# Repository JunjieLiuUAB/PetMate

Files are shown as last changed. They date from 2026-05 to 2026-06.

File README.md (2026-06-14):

# 🐾 PetMate

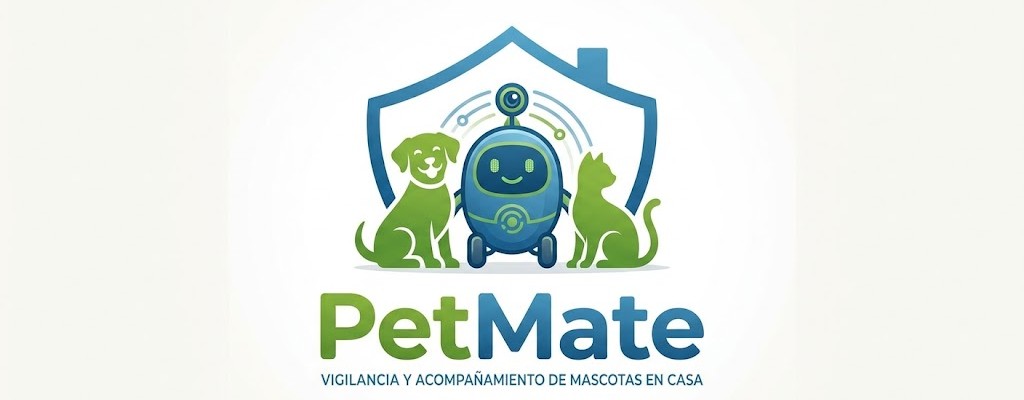
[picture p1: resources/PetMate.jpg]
PetMate Robot






[]()

> **Robot autónomo inteligente** para la vigilancia, seguridad y bienestar de tus mascotas cuando no estás en casa.

PetMate patrulla tu hogar de forma autónoma, detecta y clasifica el tipo de mascota, estima su pose en tiempo real, dispensa premios por buen comportamiento y te permite interactuar con ella a distancia desde una aplicación móvil.

---

## Tabla de Contenidos

1. [Descripción General](#descripción-general)
2. [Características Principales](#características-principales)
3. [Demo](#demo)
4. [Hardware y Componentes](#hardware-y-componentes)
   - [4.1. Componentes](#componentes)
   - [4.2. Arquitectura del Hardware](#arquitectura-del-hardware)
5. [Software y Visión Artificial](#software-y-visión-artificial)
   - [5.1. Arquitectura del Software](#arquitectura-del-software)
   - [5.2. Visión Artificial](#visión-artificial)
6. [Algoritmo de Navegación](#algoritmo-de-navegación)
7. [Instalación y Configuración](#instalación-y-configuración)
8. [Estructura del Repositorio](#estructura-del-repositorio)
9. [Referencias](#referencias)
10. [Contribuidores](#contribuidores)
11. [Licencia](#licencia)

---

## Descripción General

**PetMate** es un robot móvil autónomo diseñado para monitorizar mascotas en entornos domésticos. Combina visión artificial, Deep Learning y navegación autónoma sobre una plataforma Raspberry Pi 4 para ofrecer:

- **Vigilancia continua** de tu mascota mientras no estás en casa.
- **Identificación** del tipo de animal y **clasificación de su pose** (de pie, sentado, tumbado).
- **Interacción remota** mediante una app móvil: visualización en directo y envío de audios.
- **Dispensación de premios** automática por buen comportamiento (p. ej., sentarse a la orden).
- **Patrullaje autónomo** con evasión de obstáculos mediante algoritmo *Wall Following*.
- **Autonomía energética** gracias a un panel solar integrado.

#### Modelo 3D

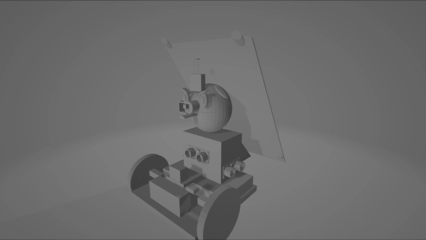
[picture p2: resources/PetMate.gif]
<p>

---

## Características Principales

| Característica | Detalle |
|---|---|
| **Detección de mascotas** | Clasificación del tipo de animal en tiempo real con modelo de Deep Learning |
| **Estimación de pose** | Detecta si la mascota está de pie, sentada o tumbada |
| **Navegación autónoma** | Algoritmo *Wall Following* implementado con 3 sensores ultrasónicos HC-SR04 |
| **Evasión de obstáculos** | Detección frontal, izquierda y derecha para esquivar obstáculos dinámicos |
| **App remota** | Streaming de vídeo en directo y control de audio desde el móvil |
| **Altavoz integrado** | Reproducción de audios enviados desde la app o alertas automáticas |
| **Dispensador de premios** | Servo-actuado: dispensa una chuche cuando detecta la secuencia correcta de comportamiento |
| **Panel solar** | Recarga continua para vigilancia prolongada sin necesidad de enchufar el robot |
| **Modelo en la nube** | Inferencia y almacenamiento gestionados remotamente mediante el proyecto *PetWatch* |
| **Notificaciones instantáneas** | Notificaciones en tiempo real de lo que está haciendo la mascota a través de la app |

---

## Demo

Vídeo demostrativo del robot PetMate en funcionamiento con todas sus funcionalidades

> **[Vídeo del robot PetMate en funcionamiento](https://drive.google.com/file/d/18QyB4_ARn3ffCMrifwrO2AGSIk0D8yak/view?usp=drive_link)** 

---

## Hardware y Componentes

En esta sección se detalla el hardware y los componentes del robot.

### Componentes

| Imagen | Componente | Unid. | Precio |
|:---:|:---|:---:|---:|
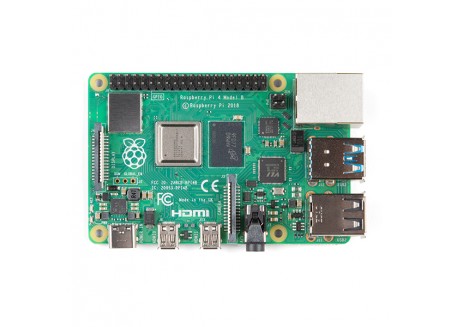
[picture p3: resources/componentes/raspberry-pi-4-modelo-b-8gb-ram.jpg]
Raspberry Pi 4
|  | Raspberry Pi 4 Modelo B — 8 GB RAM | 1 | 88,50 € |
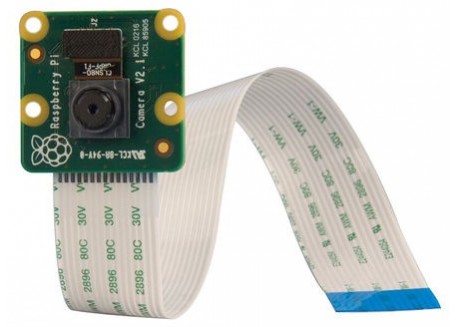
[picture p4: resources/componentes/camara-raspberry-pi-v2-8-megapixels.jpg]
Pi Camera
|  | Raspberry Pi Camera Module 2 (8 MP) | 1 | 19,95 € |
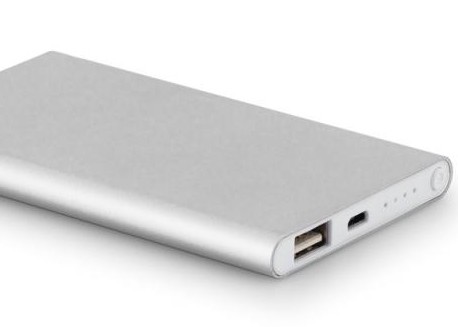
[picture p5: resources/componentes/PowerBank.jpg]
PowerBank
|  | PowerBank 10 000 mAh | 1 | 15,95 € |
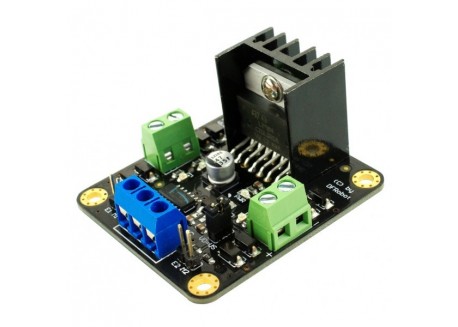
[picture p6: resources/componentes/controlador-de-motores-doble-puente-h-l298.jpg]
L298N
|  | Controlador de motores doble puente H — L298N | 1 | 15,50 € |
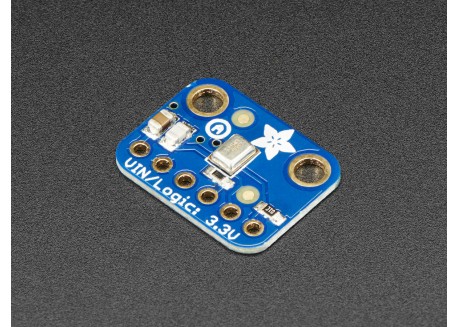
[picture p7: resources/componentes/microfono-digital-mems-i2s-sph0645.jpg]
Micrófono
|  | Micrófono electret preamplificado | 1 | 9,75 € |
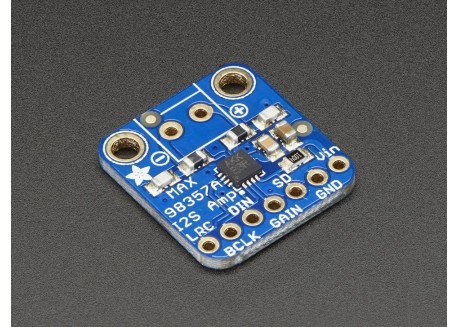
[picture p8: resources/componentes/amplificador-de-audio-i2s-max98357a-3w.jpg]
Amplificador
|  | Amplificador de audio I2s | 1 | 6,70 € |
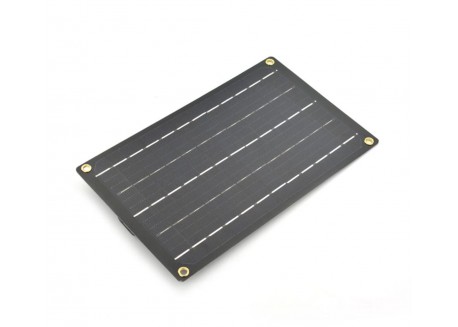
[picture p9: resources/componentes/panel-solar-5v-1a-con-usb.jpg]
Panel Solar
|  | Panel Solar 6 V / 1 W con cable | 1 | 9,95 € |
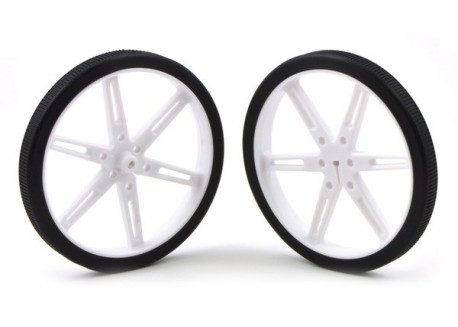
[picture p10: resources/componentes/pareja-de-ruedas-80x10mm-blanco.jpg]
Ruedas
|  | Pareja de ruedas 80×10 mm | 1 | 7,95 € |
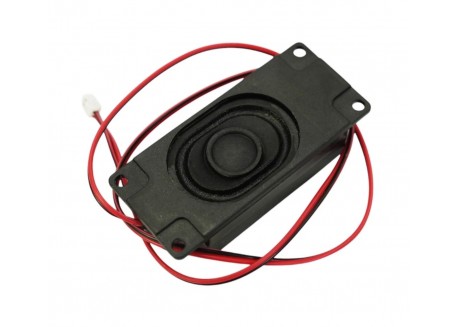
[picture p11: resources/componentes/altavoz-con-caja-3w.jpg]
Altavoz
|  | Altavoz con caja 3 W | 1 | 5,90 € |
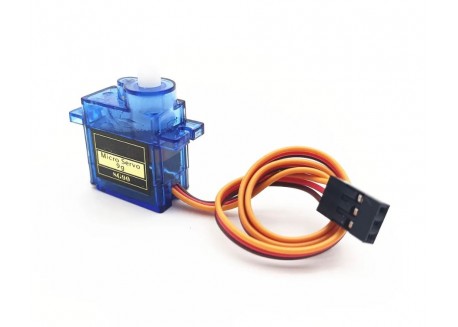
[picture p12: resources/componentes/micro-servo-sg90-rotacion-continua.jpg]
Servo
|  | Servo MG90S (dispensador) | 1 | 3,95 € |
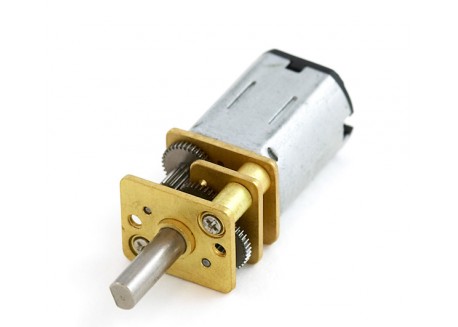
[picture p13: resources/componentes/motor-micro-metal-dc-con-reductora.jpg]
Motor
|  | Motor Micro Metal LP con reductora | 2 | 4,50 € |
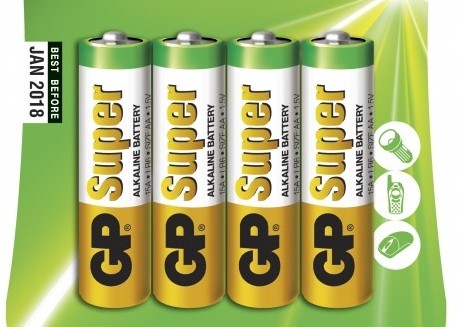
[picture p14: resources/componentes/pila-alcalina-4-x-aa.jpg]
Pilas
|  | Pilas Alcalinas 4×AA | 1 | 2,99 € |
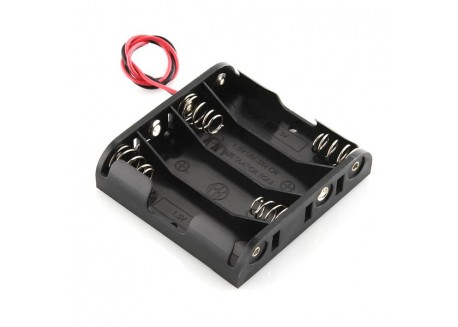
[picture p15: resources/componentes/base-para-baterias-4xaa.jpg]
Base pilas
|  | Base para pilas 4×AA | 1 | 2,00 € |
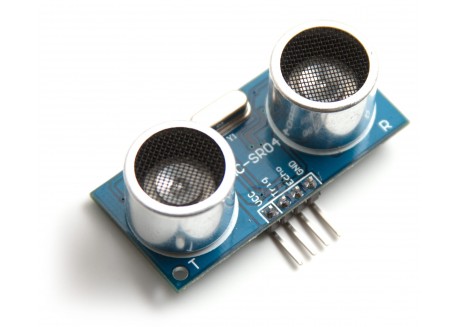
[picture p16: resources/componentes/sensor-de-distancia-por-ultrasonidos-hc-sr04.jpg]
HC-SR04
|  | Sensor ultrasónico HC-SR04 | 3 | 1,80 € |
| | | **TOTAL** | **203,49 €** |

El coste total estimado del hardware es de **203,49 €**.

### Arquitectura del Hardware

En este apartado se describe cómo se conecta todos los componentes hardware del robot para garantizar su correcto funcionamiento.

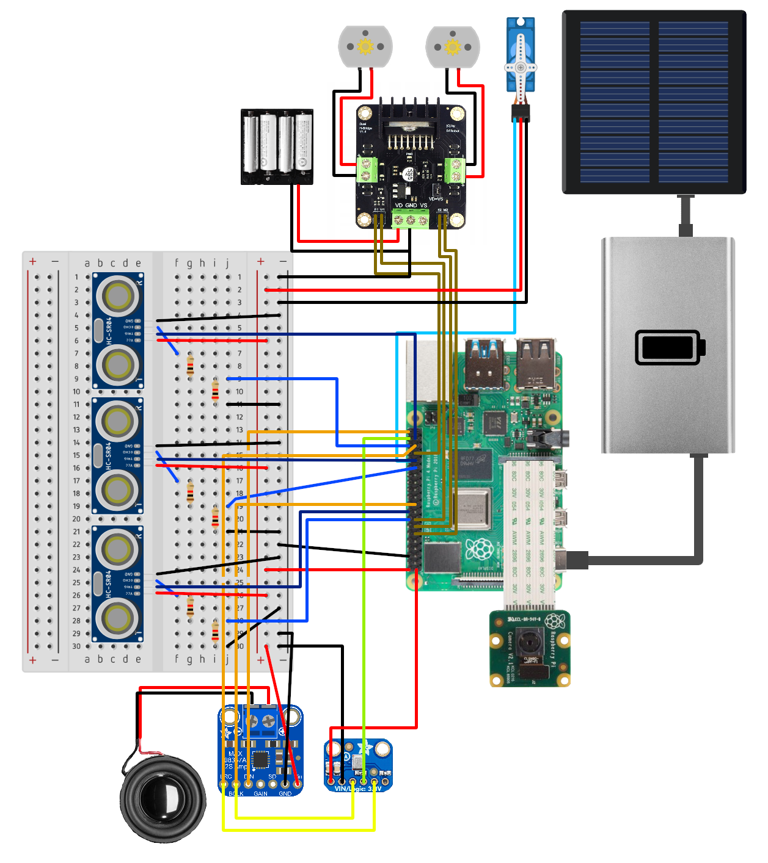
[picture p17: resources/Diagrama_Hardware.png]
Diagrama de la arquitectura del hardware


---

## Software y Visión Artificial

En esta sección se describe los detalles del software y la visión artifical de nuestro proyecto.

### Arquitectura del Software

En este apartado se detalla con un diagrama la arquitectura del software de los diversos módulos interconectados del robot, explicando cómo se comunica y colabora cada componente para garantizar el correcto funcionamiento de nuestro robot PetMate.

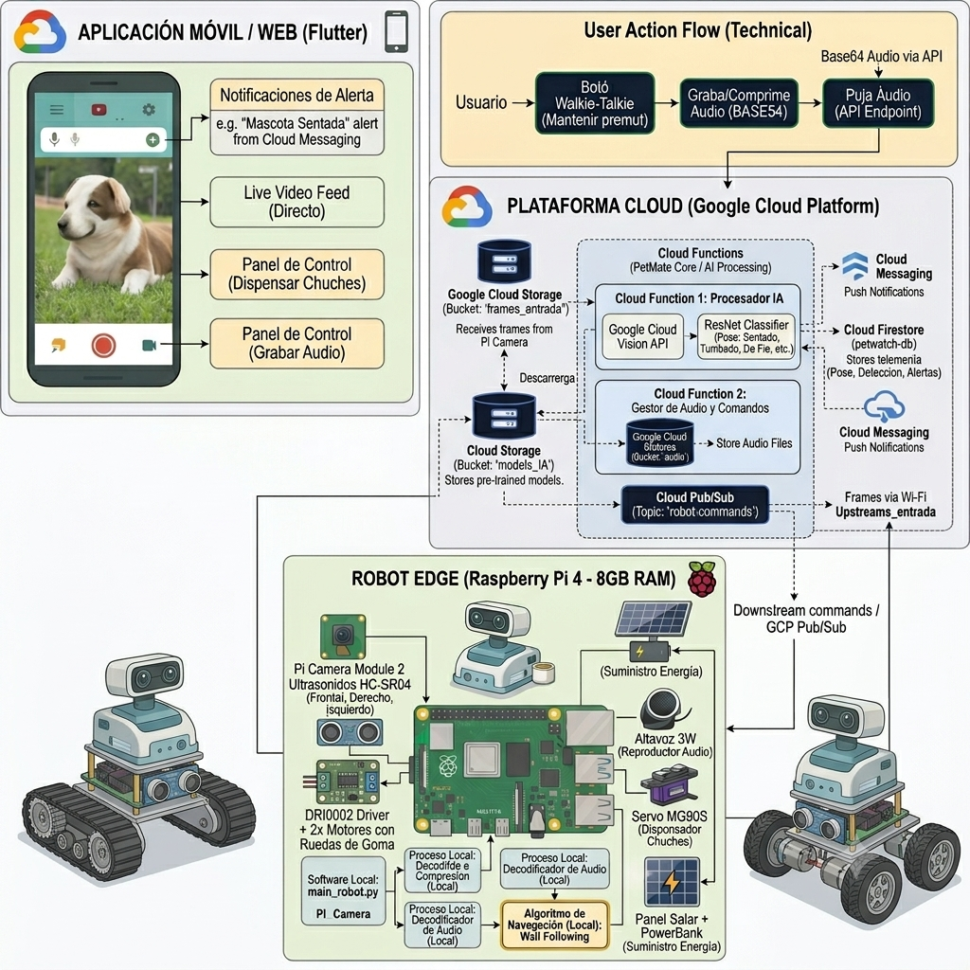
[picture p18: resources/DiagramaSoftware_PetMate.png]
Diagrama de la arquitectura de software


### Visión Artificial

El pipeline de visión artificial se estructura en dos etapas en cascada:

#### 1. Detección del tipo de mascota
- Modelo de detección de objetos entrenado con técnicas de **Deep Learning y YOLOv8** (También optamos por el uso de una Google Cloud Vision API para mejores resultados).
- Procesa el flujo de vídeo en tiempo real desde la **Pi Camera Module 2**.
- Clasifica el animal detectado (perro, gato, etc.).

#### 2. Estimación de pose
Una vez identificado el animal, un segundo modelo clasifica su estado postural:

| Pose | Descripción |
|---|---|
| De pie | El animal está erguido sobre sus patas |
| Sentado | El animal está sentado |
| Tumbado | El animal está estirado en el suelo |

#### Infraestructura Cloud — PetWatch

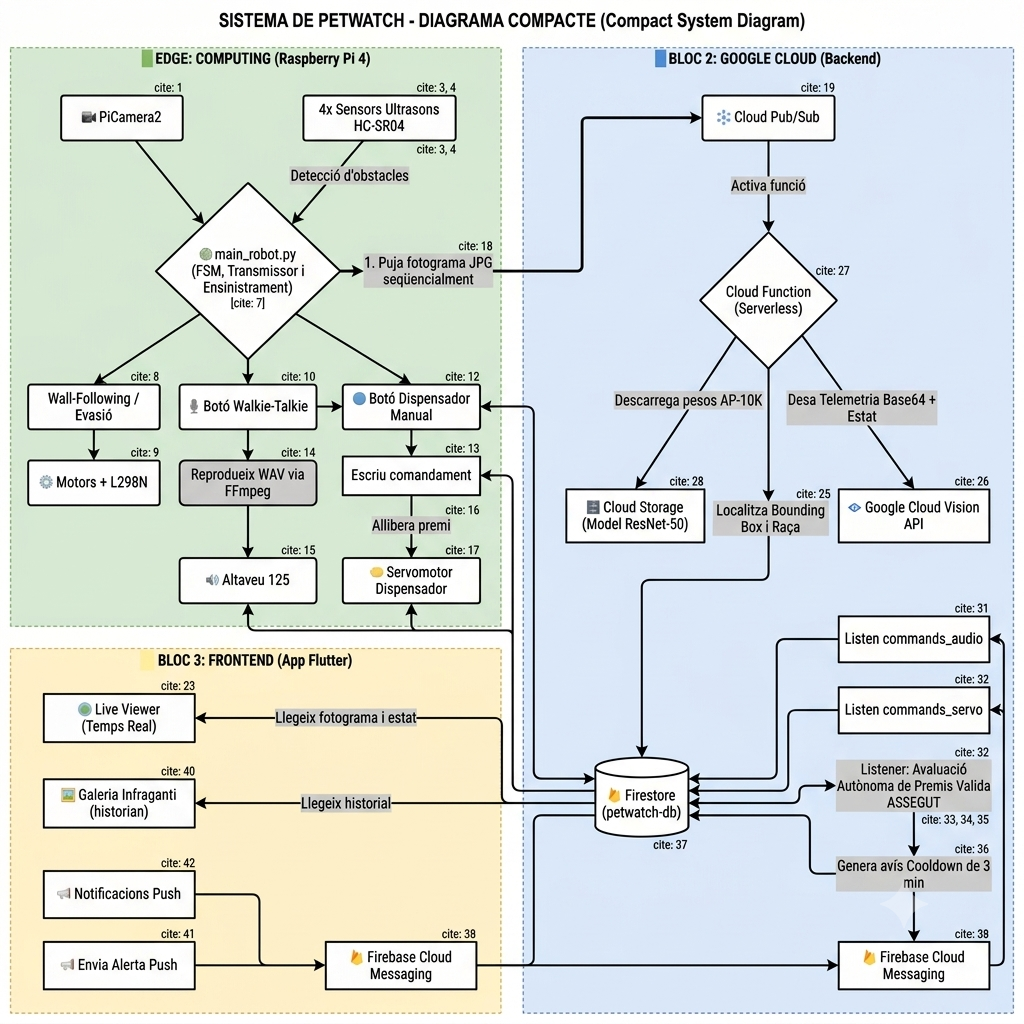
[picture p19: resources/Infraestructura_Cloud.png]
<p>
   
El modelo de inferencia está desplegado en la nube a través del proyecto **[PetWatch](📂 PetWatch)**, que también gestiona:
- Streaming de vídeo hacia la app móvil.
- Recepción y reproducción de audios enviados por el usuario.
- Almacenamiento de eventos y alertas.

**Stack tecnológico:**
* **Robot Edge (Raspberry Pi 4):** `picamera2` (captura de vídeo), `opencv-python` (compresión de frames y decodificación de audio), `RPi.GPIO` (control de motores DRI0002, servo y sensores HC-SR04) y `numpy`.
* **Plataforma Cloud (GCP & Firebase):** `functions-framework` (Cloud Functions), `torch` y `torchvision` (Inferencia YOLOv8 y ResNet), `google-cloud-pubsub` (comandos en tiempo real), `google-cloud-storage` (buckets de imágenes/audios) y `google-cloud-firestore` / `firebase-admin` (base de datos y alertas).

---

## Algoritmo de Navegación

PetMate implementa un algoritmo de **Wall Following** para patrullar el hogar de forma estructurada:

```
┌─────────────────────────────────────────────────────────────┐
│                   LÓGICA DE NAVEGACIÓN                      │
│                                                             │
│  ┌──────────────────────────────────────────────────────┐   │
│  │ Sensor DERECHO detecta pared                         │   │
│  │                                                      │   │
│  │  · Demasiado cerca  →  Ajustar: girar a la izquierda │   │
│  │  · Distancia ideal  →  Seguir recto                  │   │
│  │  · Demasiado lejos  →  Ajustar: girar a la derecha   │   │
│  └──────────────────────────────────────────────────────┘   │
│                                                             │
│  ┌──────────────────────────────────────────────────────┐   │
│  │ Sensor FRONTAL detecta obstáculo  →  Girar izquierda │   │
│  └──────────────────────────────────────────────────────┘   │
│                                                             │
│  ┌──────────────────────────────────────────────────────┐   │
│  │ Sensor IZQUIERDO detecta obstáculo  →  Girar derecha │   │
│  └──────────────────────────────────────────────────────┘   │
│                                                             │
│  ┌──────────────────────────────────────────────────────┐   │
│  │ Pared detectada lejos  →  Girar izquierda hasta      │   │
│  │                          encontrar pared por derecha │   │
│  │ Sin pared detectada  →  Seguir recto hasta encontrar │   │
│  │                               pared de frente        │   │
│  └──────────────────────────────────────────────────────┘   │
└─────────────────────────────────────────────────────────────┘
```

El robot mantiene siempre una pared a su **derecha**, recorriendo el perímetro de las habitaciones de forma sistemática. Los tres sensores HC-SR04 (frontal, izquierdo, derecho) permiten detectar y esquivar obstáculos dinámicos como muebles o personas.

---

## Instalación y Configuración

Sigue estos pasos para clonar el proyecto, instalar todo lo necesario y configurar el entorno en tu Raspberry Pi 4

### Requisitos previos

Antes de comenzar, asegúrate de tener lo siguient en tu Raspberry Pi:
- Raspberry Pi 4 con Raspberry Pi OS (64-bit)
- Python 3.11+
- Conexión WiFi activa

### Pasos de instalación

**1. Clonar el repositorio:**

```bash
git clone https://github.com/TU_USUARIO/PetMate.git
cd PetMate
```

**2. Instalar dependencias:**

```bash
pip install -r requirements.txt
```

**3. Configurar credenciales de la nube (PetWatch):**

```bash
cp config/config.example.yaml config/config.yaml
```

**4. Ejecutar el robot:**

```bash
python src/main.py
```

---

## Estructura del Repositorio

```
PetMate/
│
├── 📂 3D designs/       # Modelos CAD y archivos STL de la estructura del robot
├── 📂 PetWatch/         # Módulo de visión por computador y servidor en la nube
├── 📂 src/              # Código fuente Python ejecutable en la Raspberry Pi
│   ├── main.py                # Punto de entrada principal (gestión de hilos y actuadores)
│   ├── navigation.py          # Algoritmo de navegación autónoma (Wall Following)
│   ├── motors.py              # Control de tracción y controlador de motores (DRI0002)
│   ├── ultrasonic.py          # Drivers de lectura para los sensores de distancia (HC-SR04)
│   ├── dispenser_servo.py     # Control del servomotor para la liberación de comida
│   ├── audio_input.py         # Captura de audio digital (micrófono I2S SPH0645)
│   └── audio_output.py        # Reproducción de sonido (amplificador I2S MAX98357A)
└── 📂 resources/        # Diagramas, arquitectura, fotos de componentes
```

---

## Referencias

- [Wall Following Algorithm](https://iamzxlee.wordpress.com/2014/06/21/wall-following-robot/) 
- [Ultralytics, “YOLO8 Models,” Ultralytics Documentation](https://docs.ultralytics.com/es/models/yolov8)
- [Raspberry Pi Documentation](https://www.raspberrypi.com/documentation/)
- [HC-SR04 Ultrasonic Sensor Datasheet](https://cdn.sparkfun.com/datasheets/Sensors/Proximity/HCSR04.pdf)
- [Diseño y construcción de un robot de vigilancia](https://ru.dgb.unam.mx/server/api/core/bitstreams/b9e9041b-f1f8-48f6-aa99-0d780be3b49f/content)
- [Programación de robot móvil para vigilancia con visión artificial](https://riunet.upv.es/server/api/core/bitstreams/732d7050-a3f3-4cd7-b9b0-4206617300e7/content)

---

## Contribuidores

| Nombre | GitHub |
|---|---|
| Junjie Liu |  [@NIU1708478](https://github.com/JunjieLiuUAB) |
| Joel Rillo Fernández | [@NIU1708430](https://github.com/NIU1708430) |
| Gerard Saez Salat | [@gsaez22](https://github.com/gsaez22) |
| Elías Pascual Paz | [@Elías](https://github.com/NIU1672946) |

---

## Licencia

Este proyecto está bajo la licencia **MIT**. Consulta el archivo [LICENSE](LICENSE) para más detalles.



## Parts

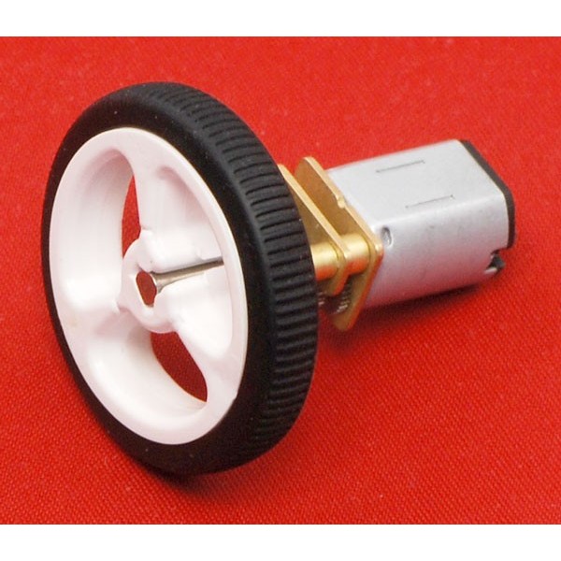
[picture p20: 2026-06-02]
resources/componentes/rueda-de-goma-32x7mm.jpg

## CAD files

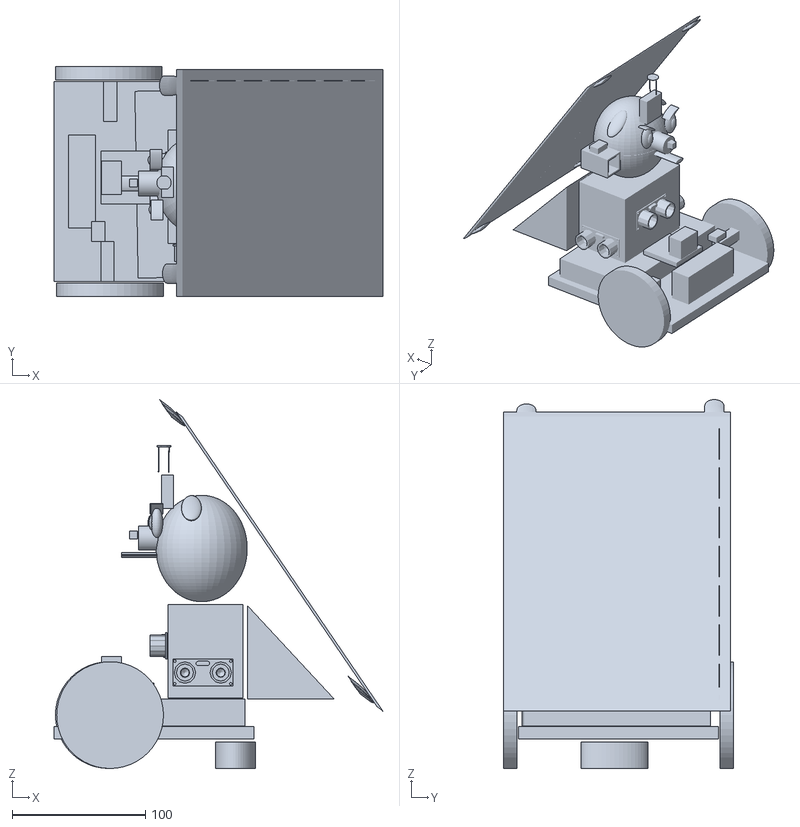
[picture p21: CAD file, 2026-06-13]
3D designs/ROBOTV2.stl
246.5 x 172.0 x 276.5

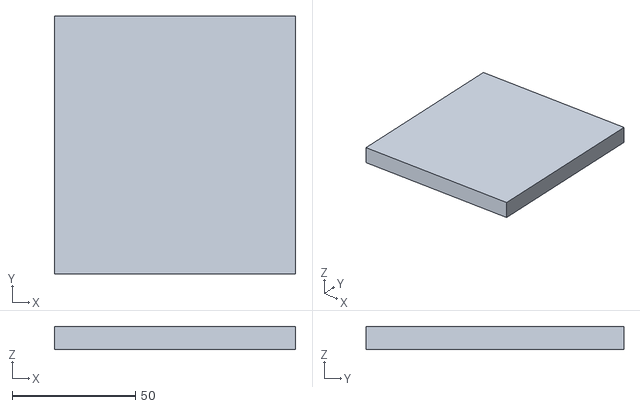
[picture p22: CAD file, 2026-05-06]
3D designs/Super Jarv-Bombul-5.stl
98.0 x 104.8 x 9.50

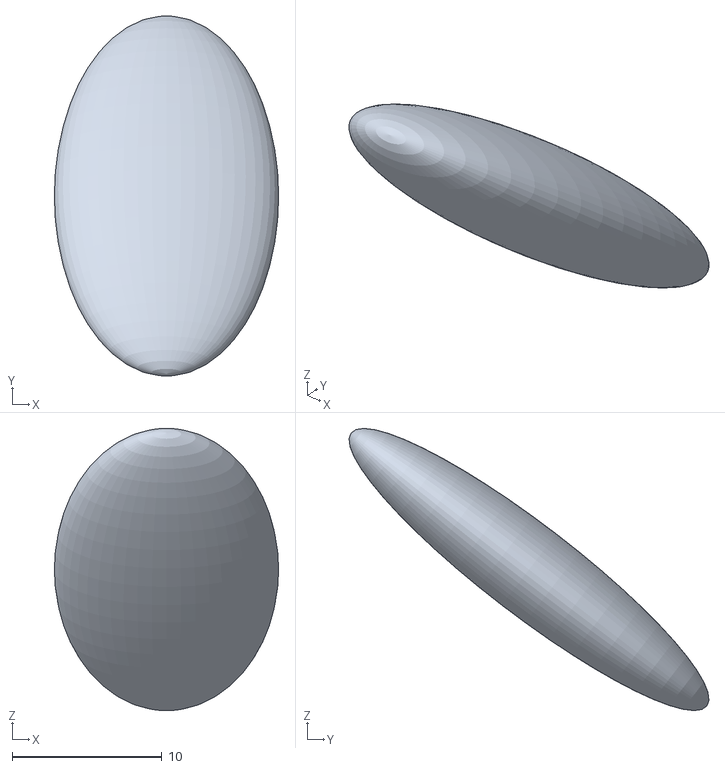
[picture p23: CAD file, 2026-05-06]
3D designs/Super Jarv-Bombul-9.stl
15.0 x 24.1 x 18.9

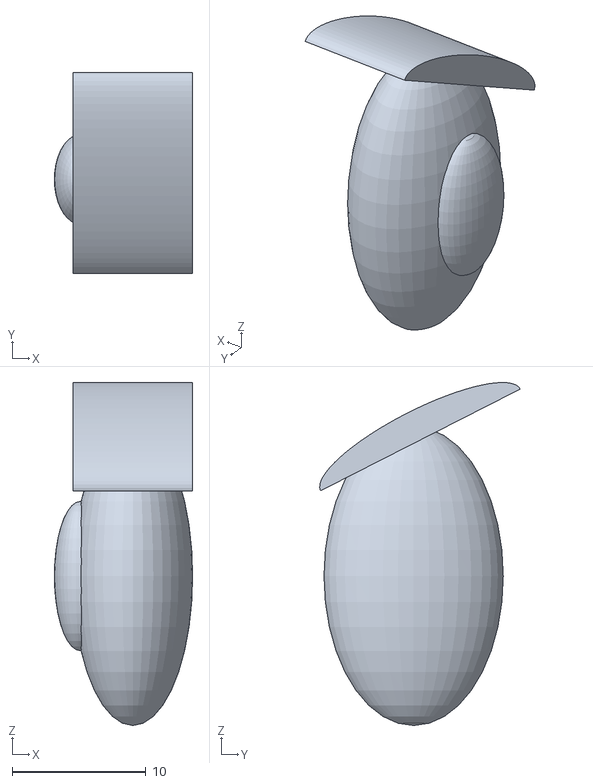
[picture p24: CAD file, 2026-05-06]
3D designs/Super Jarv-Bombul-10.stl
10.3 x 15.0 x 25.7

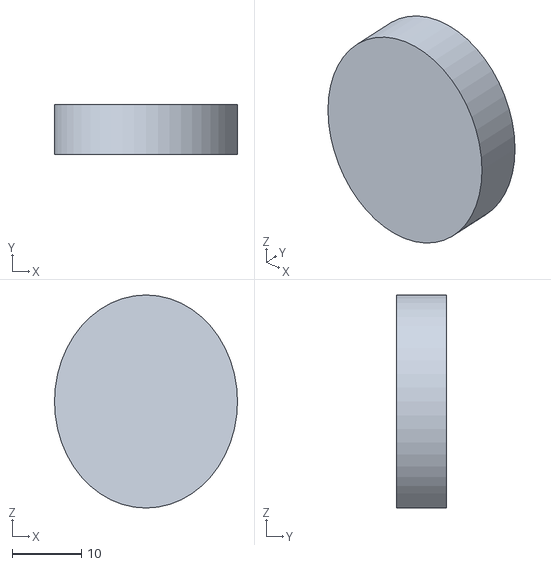
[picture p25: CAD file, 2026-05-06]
3D designs/Super Jarv-Bombul-4.stl
26.4 x 7.27 x 30.8

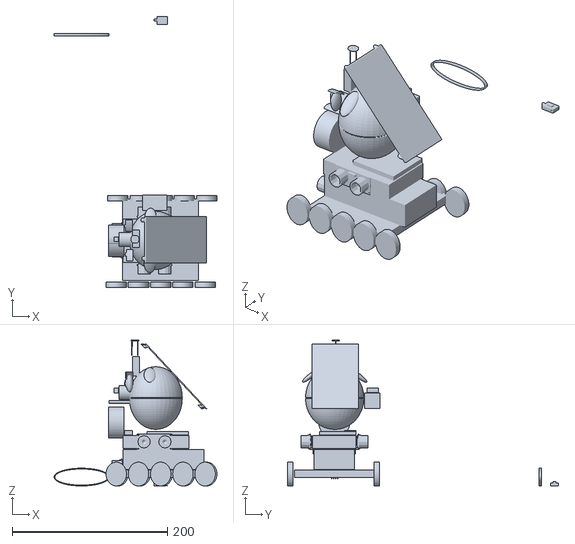
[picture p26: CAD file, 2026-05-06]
3D designs/Super Jarv-Bombul-3.stl
210.0 x 349.3 x 188.1

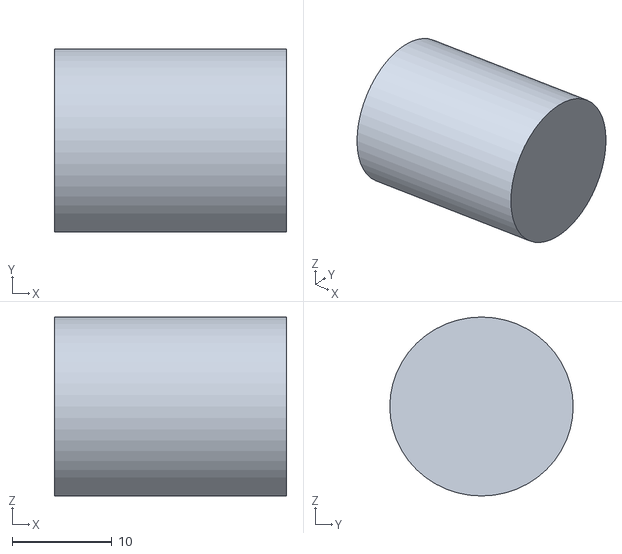
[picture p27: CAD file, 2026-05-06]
3D designs/Super Jarv-Bombul-11.stl
23.3 x 18.4 x 17.9

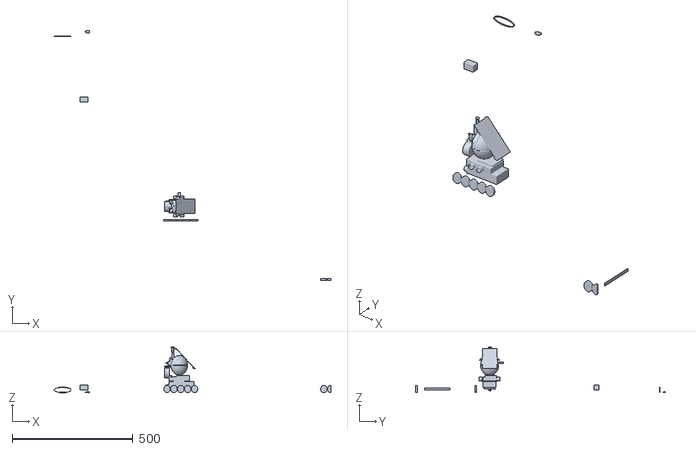
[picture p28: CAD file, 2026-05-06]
3D designs/Super Jarv-Bombul-6.stl
1146.0 x 1034.3 x 188.1

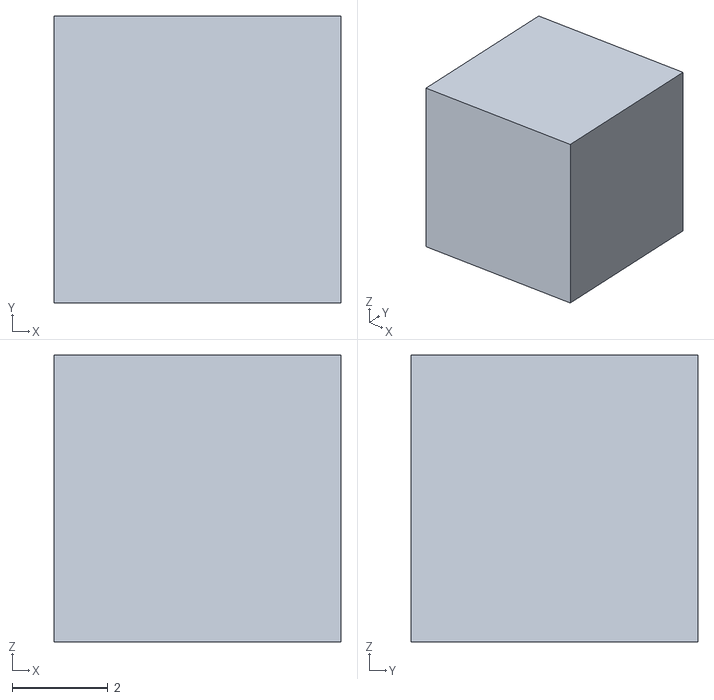
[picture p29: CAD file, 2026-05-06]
3D designs/Super Jarv-Bombul-12.stl
6.00 x 6.00 x 6.00

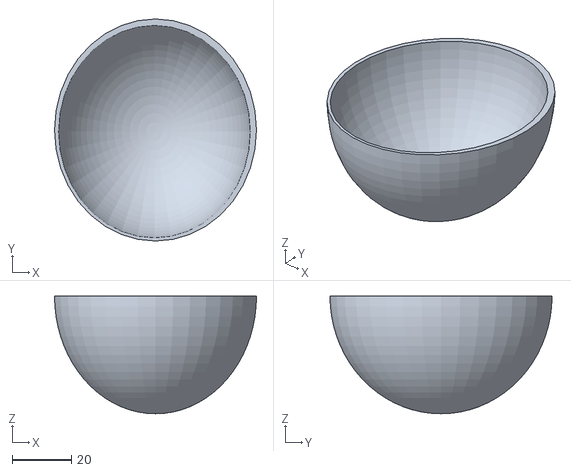
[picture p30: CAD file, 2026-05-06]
3D designs/Super Jarv-Bombul-8.stl
68.3 x 75.1 x 39.7

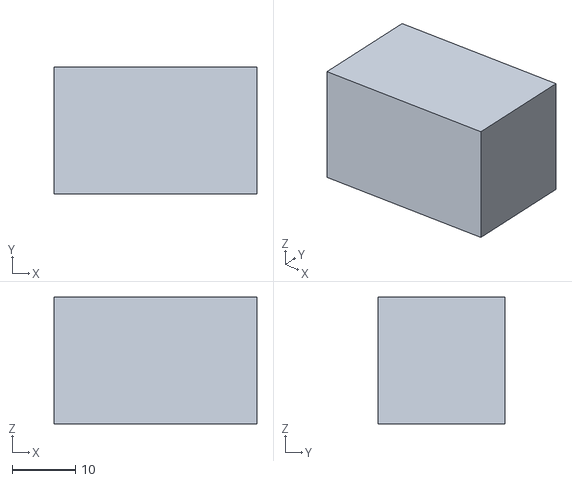
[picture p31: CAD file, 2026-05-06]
3D designs/Super Jarv-Bombul-7.stl
32.0 x 20.0 x 20.0

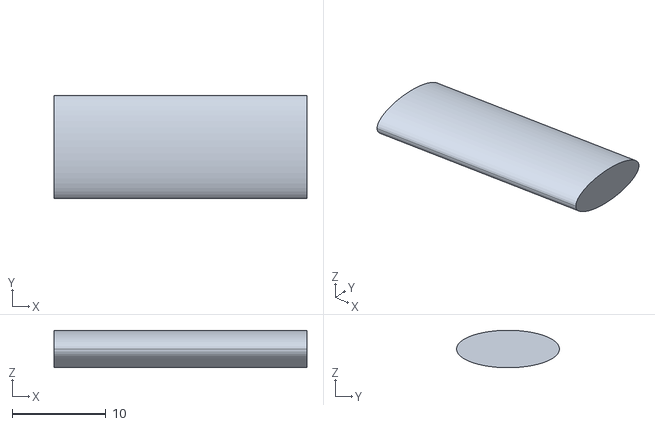
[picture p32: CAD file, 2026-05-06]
3D designs/Super Jarv-Bombul-13.stl
27.0 x 11.0 x 4.00

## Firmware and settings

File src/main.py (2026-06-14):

import os
import sys
import time
import threading

os.environ["GPIOZERO_PIN_FACTORY"] = "lgpio"

SRC_DIR = os.path.dirname(os.path.abspath(__file__))
ROOT_DIR = os.path.dirname(SRC_DIR)
PETWATCH_CLIENT_DIR = os.path.join(ROOT_DIR, "PetWatch-G2_5-main", "backend", "edge_client")

if ROOT_DIR not in sys.path:
    sys.path.append(ROOT_DIR)
if PETWATCH_CLIENT_DIR not in sys.path:
    sys.path.append(PETWATCH_CLIENT_DIR)

from src.dispenser_servo import dar_comida
from src.navigation import iniciar_navegacion_autonoma

try:
    from conectar_camara import main as iniciar_streaming_camara
    from escuchador_audio import coleccion_audio_ref, reproducir_audio
    CLOUD_AVAILABLE = True
except ImportError as e:
    print(\f"⚠️ No se pudieron cargar módulos de PetWatch. Verifica los nombres de archivos. Error: {e}")
    CLOUD_AVAILABLE = False

def main():
    print("==============================================")
    print("        INICIANDO ECOCONEXIÓN PETMATE         ")
    print("==============================================")

    sistema_activo = threading.Event()
    sistema_activo.set()

    HILOS = []

    hilo_motores = threading.Thread(
        target=iniciar_navegacion_autonoma, 
        args=(sistema_activo,), 
        name="Hilo-Navegacion"
    )
    hilo_motores.daemon = True 
    HILOS.append(hilo_motores)

    if CLOUD_AVAILABLE:
        hilo_camara = threading.Thread(
            target=iniciar_streaming_camara, 
            name="Hilo-Camara"
        )
        hilo_camara.daemon = True
        HILOS.append(hilo_camara)
        
        print("[SISTEMA] Conectando escuchador asíncrono de Firestore...")
        observador_firestore = coleccion_audio_ref.on_snapshot(reproducir_audio)

    for hilo in HILOS:
        print(f"[SISTEMA] Arrancando: {hilo.name}")
        hilo.start()

    print("\n[OK] Todo el ecosistema está en marcha de forma síncrona.")
    print("Presiona Ctrl + C para apagar el robot de forma segura.\n")

    try:
        while True:
            time.sleep(1)
            
    except KeyboardInterrupt:
        print("\n\n🛑 [APAGADO] Solicitud de parada manual detectada.")
    finally:
        print("[APAGADO] Desactivando banderas y deteniendo actuadores...")
        sistema_activo.clear() 
        if CLOUD_AVAILABLE:
            print("[APAGADO] Removiendo observador de Firebase...")
            observador_firestore.unsubscribe()
        time.sleep(0.5)
        print("[OK] Robot PetMate apagado de forma segura.")

if __name__ == "__main__":
    main()

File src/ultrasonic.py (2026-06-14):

import time
from gpiozero import DistanceSensor

class HCSR04:
    """
    Drivers para Raspberry Pi 4 para los sonsores HC-SR04 
    """
    def __init__(self, trigger_pin, echo_pin):
        # gpiozero maneja internamente los tiempos de espera y usa la numeración de pines BCM por defecto
        self._sensor = DistanceSensor(echo=echo_pin, trigger=trigger_pin, max_distance=4.0)

    def distance_cm(self):
        """
        devuelve la distancia en centímetros (float).
        """
        # gpiozero entrega la distancia en metros pero se pasa a cm
        return self._sensor.distance * 100



if __name__ == "__main__":
    print("Iniciando los 3 sensores ultrasónicos...")
    
    sensor_cen = HCSR04(trigger_pin=5, echo_pin=6)
    sensor_der = HCSR04(trigger_pin=26, echo_pin=12)
    sensor_izq = HCSR04(trigger_pin=23, echo_pin=24)
    
    #sensor_izq = HCSR04(trigger_pin=26, echo_pin=12)
    #sensor_der = HCSR04(trigger_pin=23, echo_pin=24)
    #izquierod y derecho al reves estan asi que:

    try:
        while True:
            d_izq = sensor_izq.distance_cm()
            d_cen = sensor_cen.distance_cm()
            d_der = sensor_der.distance_cm()
            
            print(f"Izquierda: {d_izq:.1f} cm | Centro: {d_cen:.1f} cm | Derecha: {d_der:.1f} cm")
            #print(f"Centro: {d_cen:.1f} cm | Derecha: {d_der:.1f} cm")
            #print(f"Derecha: {d_der:.1f} cm")
            #print(f"Centro: {d_cen:.1f} cm")
            
            # Pausa  
            time.sleep(0.2)
            
    except KeyboardInterrupt:
        print("\nPrograma detenido por el usuario.")

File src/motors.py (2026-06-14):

import os
os.environ["GPIOZERO_PIN_FACTORY"] = "lgpio"

from gpiozero import PhaseEnableMotor
from time import sleep

# Configuración de pines para DRI0002
M1_DIR = 17  
E1_PWM = 13  
M2_DIR = 22  
E2_PWM = 27  

motor_izquierdo = PhaseEnableMotor(phase=M1_DIR, enable=E1_PWM)
motor_derecho = PhaseEnableMotor(phase=M2_DIR, enable=E2_PWM)

def avanzar():
    motor_izquierdo.forward()
    motor_derecho.forward()

def retroceder():
    motor_izquierdo.backward()
    motor_derecho.backward()

def detener():
    motor_izquierdo.stop()
    motor_derecho.stop()

def girar_derecha():
    motor_izquierdo.forward()
    motor_derecho.backward()


print("Iniciando prueba de motores (Sentido corregido por Software)...")
print("Asegúrate de que las ruedas tengan espacio para girar libremente.\n")

try:
    while True:
        print("Avanzando...")
        avanzar()
        sleep(2.0)

        print("Deteniendo motores...")
        detener()
        sleep(1.0)
        
        print("Retrocediendo...")
        retroceder()
        sleep(2.0)

        print("Deteniendo motores...")
        detener()
        sleep(1.0)

except KeyboardInterrupt:
    detener()
    print("\nPrueba finalizada y motores detenidos.")

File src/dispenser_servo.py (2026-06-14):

import os
os.environ["GPIOZERO_PIN_FACTORY"] = "lgpio"

from gpiozero import Servo
from time import sleep

MIN_PULSE = 0.5 / 1000
MAX_PULSE = 2.5 / 1000

servo = Servo(4, min_pulse_width=MIN_PULSE, max_pulse_width=MAX_PULSE)

def dar_comida():
    print("[HARDWARE] Activando dispensador de comida...")
    servo.max() 
    time.sleep(1.5)
    servo.value = -0.70 
    time.sleep(1.5)
    servo.value = None 


"""
#Test
print("Iniciando control del servo MG90S...")

try:
    while True:
        print("Ángulo: 90°")
        servo.max()
        sleep(1.5)

        
        print("Ángulo: 45°")
        servo.value = -0.70
        sleep(1.5)

        
        #print("Ángulo: 180°")
        #servo.max()
        #sleep(1.5)
        

except KeyboardInterrupt:
    servo.value = None
    print("\nPrograma detenido.")
    """

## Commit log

2026-05-06 Robot .stl 3D models
    [Super Jarv-Bombul-13.stl]
2026-05-06 .stl files
    [Super Jarv-Bombul-10.stl, Super Jarv-Bombul-11.stl, Super Jarv-Bombul-12.stl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]
2026-05-19 Create carpeta circuits
2026-05-20 Add main.py to read ultrasonic sensor distance
2026-05-20 Add camera streaming functionality with Pub/Sub
2026-06-02 Add wheel and motor entry to components list
2026-06-03 Update PowerBank image format in README.md
2026-06-03 Update Motor Micro Metal price and total cost
2026-06-14 Refactor main.py for threading and module imports
2026-06-14 Refactor audio configuration and device search
2026-06-14 Implement food dispensing function
    Added a function to activate the food dispenser servo.
2026-06-14 Refactor motor control functions and remove comments
    Removed commented-out code and cleaned up motor control functions.
2026-06-14 Fix sensor initialization order in ultrasonic.py
    [ultrasonic.py]
2026-06-14 Fix: Submódulo PetWatch vinculado a la rama G2_5
2026-06-14 Fix: Submódulo enlazado correctamente a la rama G2_5
2026-06-14 Fix total: Activando enlace de submódulo en GitHub

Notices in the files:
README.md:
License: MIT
